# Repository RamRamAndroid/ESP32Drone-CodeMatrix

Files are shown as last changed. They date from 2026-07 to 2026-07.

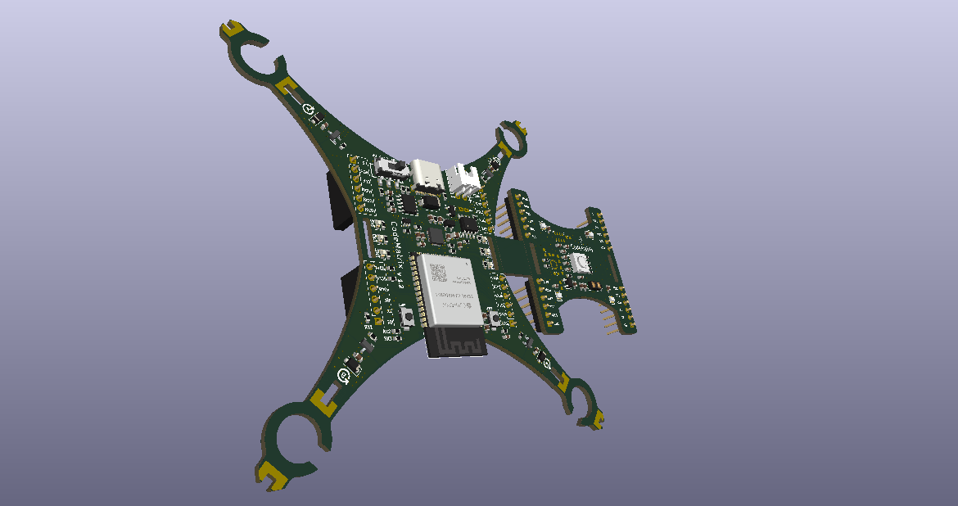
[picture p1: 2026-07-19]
Drone + Module/KiCad Files/panel.png

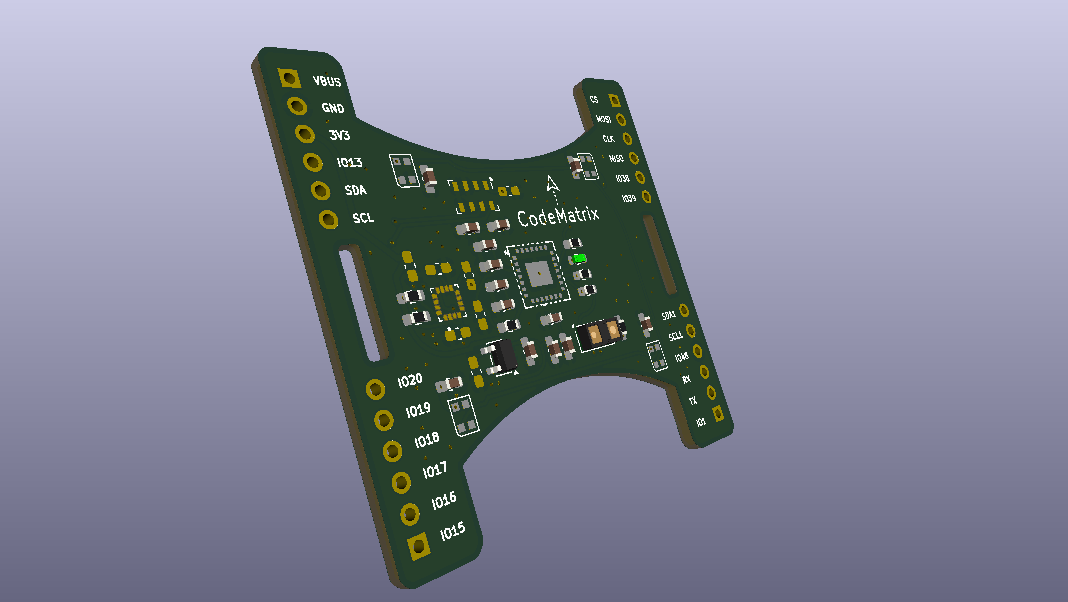
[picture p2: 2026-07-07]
Module/KiCAD Files/B1.png

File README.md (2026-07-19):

## Introduction Of CodeMatrix ESP32 Drone
drone
drone

CodeMatrix ESP32 Drone is a compact, WiFi-controlled drone based on the ESP32-S3 microcontroller. Designed for hobbyists, makers, and engineers, CodeMatrix ESP32 Drone offers a simple yet powerful platform for drone experimentation and development. It is an open-hardware project, making it easy to modify and expand.

Whether you’re new to drones or an experienced developer looking to create custom flight applications, LiteWing provides an accessible and affordable way to explore drone technology. Unlike traditional drones that require proprietary controllers, CodeMatrix ESP32 Drone connects to your smartphone, allowing for an intuitive flying experience without additional hardware.

The firmware on CodeMatrix ESP32 Drone supports Crazyflie cfclient and cflib, meaning you can program and control your drone using Python and add more features like height hold, position hold, gesture control, and more.

The latest version includes more GPIO pins, sensor mounts, LED indicators to make it easier to tinker with and program. The PCB frame design keeps it lightweight while reducing costs, making it one of the most affordable DIY drones available.

### Note:- The Files Related To The Drone Are In The Folder Named "Drone"

## Introduction Of CodeMatrix ESP32 Drone Positioning Module
WhatsApp Image 2026-07-04 at 12 35 27 AM
B-ezgif com-optimize (1)

The ESP32 Drone Positioning Module is a plug-and-play optical flow and ToF-based stabilization add-on designed for indoor and GPS-denied flight. Featuring the PMW3901 optical flow sensor for precise X/Y position tracking and the VL53L1X Time-of-Flight sensor for accurate height measurement, this module enables stable height hold and position hold performance. Ideal for DIY drones, autonomous flight experiments, and educational robotics projects.

This module transforms your CodeMatrix ESP32 Drone and Litewing Drone into a fully-equipped autonomous flight platform by adding critical sensor capabilities: precision ToF height measurement, optical motion tracking, and visual status feedback. All connected through a 24-pin connector, eliminating complex wiring while maintaining robust electrical connections suitable for flight operations.

This add-on module is completely compatible with the CodeMatrix ESP32 Drone and LiteWing Drones and consists of the VL53L1x ToF sensor and PMW3901MB optical flow sensor for height hold and position hold, respectively. Apart from this, the module also has 4 Neopixel LEDs that can be programmed to indicate flight status or for visual appeal.

Important: By default, only the ToF sensor, Optical Flow sensor, and Neopixel LEDs will be soldered on the module. The brometric sensor and magnetometer footprint is added only for users who wish to build more using the same board. By default these two sensors will not be populated. The colour of the PCB might also be in black or green color depending on the time of purchase, but features and working will reamin the same.

### Note:- Files Related To The Positioning Module Are In The Folder Named "Module"

## Introduction Of ESP32 Drone Bluetooth Speaker Module (Coming Soon)

untitled-ezgif com-optimize

The ESP32 Drone Bluetooth Speaker Module is a plug-and-play lightweight Bluetooth speaker system to extend the drone's capabilities beyond flight. By adding a simple Bluetooth audio setup, the drone can now deliver real-time announcements, voice messages, or music directly from the air without requiring any additional coding. The entire system works through a standard Bluetooth connection, making it easy to set up, practical for demonstrations, events, and experimental applications while also being fun.

### Note:- Files Related To The Positioning Module Are In The Folder Named "BluetoothModule"

## Introduction Of ESP32 Drone + Positioning Module PCB
panel
panel

This PCB Has Both The Drone And Module Combined Into One PCB For Easier Manufacturing And Assembly And This Method Is Faster Than Getting The Both Seperatly

### Note:- The Files Related To The Drone + Module PCB Are In The Folder Named "drone+module"

## Add-On Module Template



I Have Made A Template Of The Positioning Module For You To Customize, It Is In The Module Folder

-------------------------------------------------------------------------------------------------------------------------------------------------

### As This Project Is Based On LiteWing, The Instructions Are The Same As Litewing Drone Instructions (https://circuitdigest.com/wiki/litewing/)

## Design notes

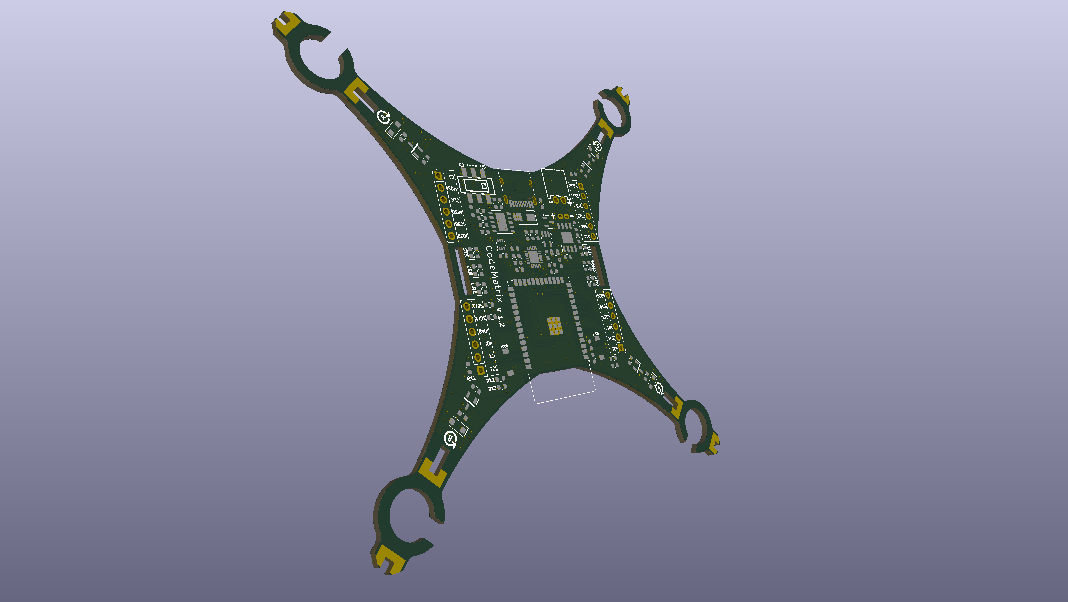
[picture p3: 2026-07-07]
Drone/KiCAD Files/drone.png

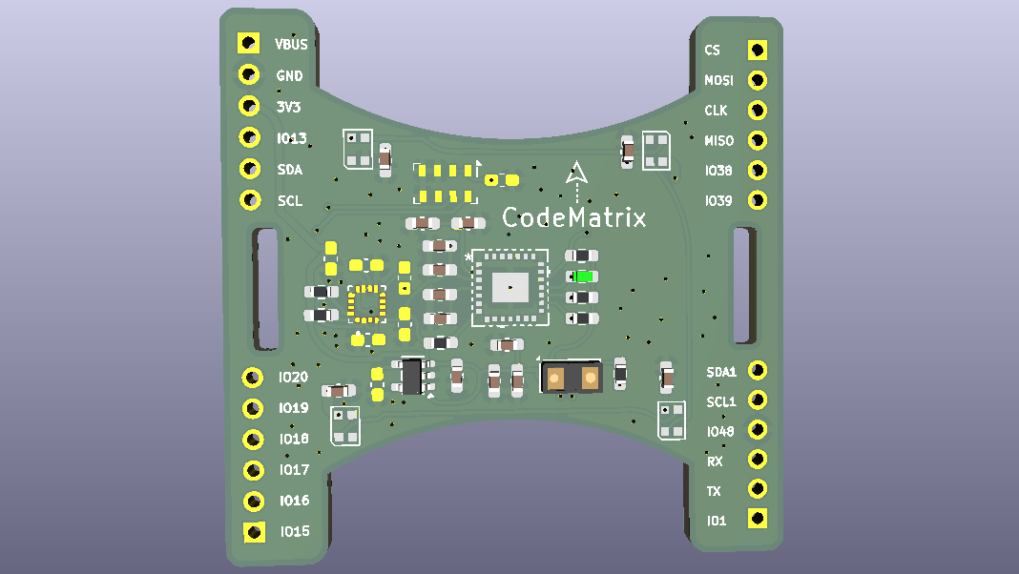
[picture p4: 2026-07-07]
Module/KiCAD Files/B.png

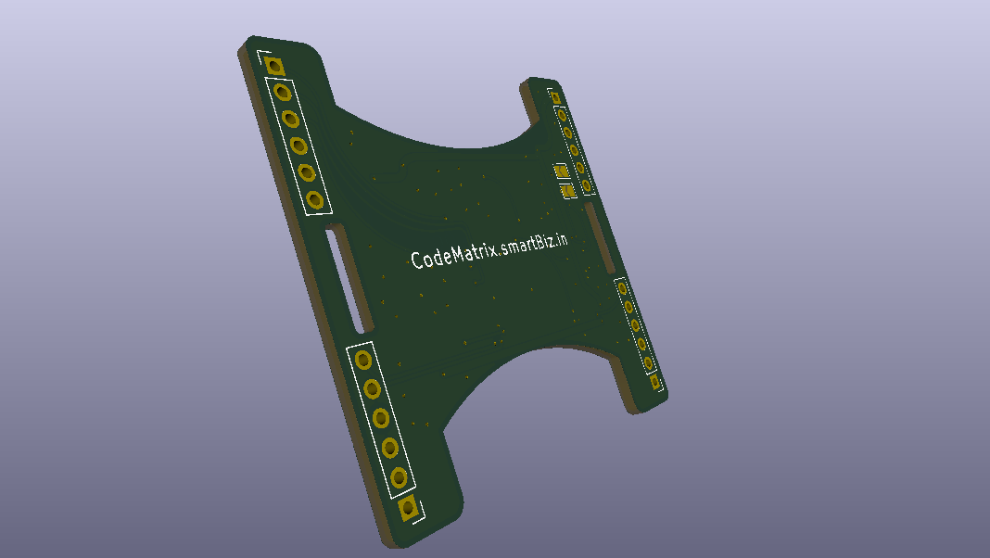
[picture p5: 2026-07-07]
Module/KiCAD Files/B3.png

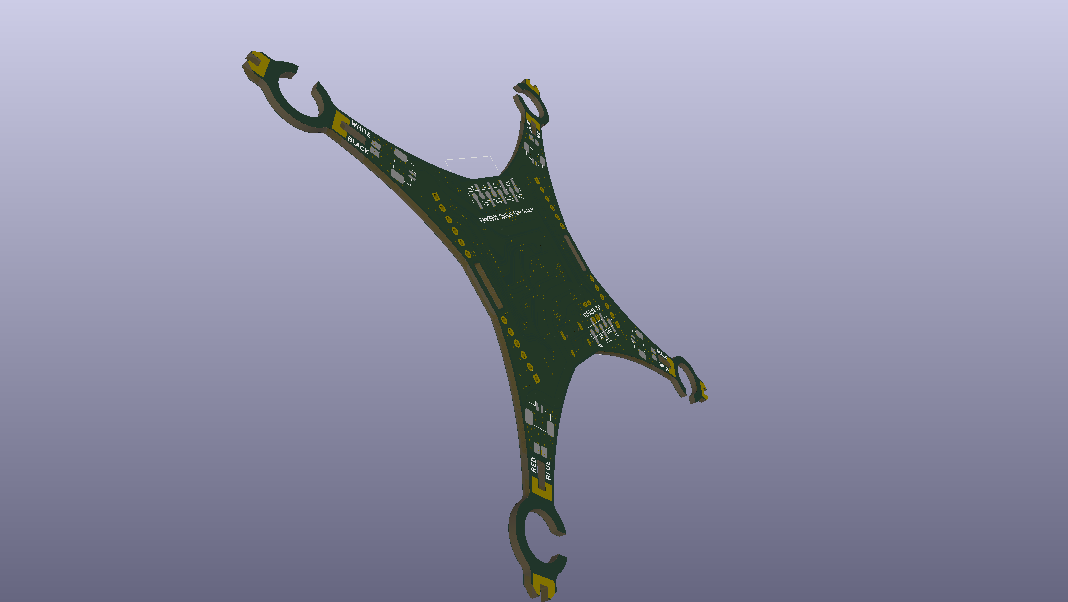
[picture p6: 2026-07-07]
Drone/KiCAD Files/drone1.png

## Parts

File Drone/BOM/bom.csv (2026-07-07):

Designator | Footprint | Quantity | Value | LCSC Part #
C1, C12, C4, C5 | 0603 | 4 | 10uF | C19702
C10, C13, C14, C6, C7, C8 | 0603 | 6 | 100nF | C14663
C11 | 0603 | 1 | 10nf | C57112
C15, C16, C17, C18 | 0603 | 4 | 1uF | C15849
C2 | 0603 | 1 | 470pF | C1620
C3 | 0805 | 1 | 2.2uF | C5448893
C9 | 0603 | 1 | 2.2nf | C1604
D1 | D_SMA | 1 | SS34 | C8678
D2, D3, D4, D5 | D_SOD-123F | 4 | 1N4148W | C81598
IC1 | SOIC127P600X175-9N | 1 | TP4056 | C20199357
J1 | USB_C_Receptacle_HRO_TYPE-C-31-M-12 | 1 | USB_C_Receptacle_USB2.0 | C2927038
J2 | CONN-TH_2P-P2.50_XH-2AW | 1 | JST XH 2P 2.50mm SMD Hoz | C33132
LED1, LED2, LED5 | 0603 | 3 | LED_Red | C2286
LED3, LED6 | 0603 | 2 | LED_Blue | C2288
LED4 | 0603 | 1 | LED_Green | C12065
R1, R2 | 0603 | 2 | 5.1K | C23186
R10, R11, R12, R13, R6, R7, R9 | 0603 | 7 | 1K | C21190
R14, R16, R17, R18, R19, R20, R21, R22, R23, R24, R25 | 0603 | 11 | 10k | C25804
R15 | 0603 | 1 | 4.7k | C23162
R26, R27, R3, R8 | 0603 | 4 | 100K | C25803
R28, R29, R30 | 0603 | 3 | 0R | C21189
R4 | 0603 | 1 | 470R | C23179
R5 | 0603 | 1 | 1.2K | C22765
SW1 | SW-SMD_MST22D18G2 | 1 | MST22D18G2_125 | C2906280
SW2, SW3 | Tactile 3x4x2mm TS-A010 | 2 | Tactile Switch 3x4x2 | C2874433
T1, T2, T3, T4 | SOT95P237X112-3N | 4 | IRLML6344TRPBF | C6285738
U1 | SOT-23 | 1 | AO3401A | C15127
U2 | SOT-23-5 | 1 | SPX3819M5-L-3-3/TR | C9055
U5 | ESSOP-10_3.9x4.9mm_P1.00mm | 1 | CH340K | C18208922
U6 | SOT-363_SC-70-6 | 1 | 2N27002DW | C5190214
U7 | MPU6050 | 1 | MPU-6050 | C24112
U8 | ESP32-S3-WROOM-1 | 1 | ESP32-S3-WROOM-1 | C2913198

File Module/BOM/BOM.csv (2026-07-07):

Id | Designator | Footprint | Quantity | Designation | Supplier and ref
1 | C1, C3, C5 | C_0603_1608Metric_Pad1.08x0.95mm_HandSolder | 3 | 10uF
2 | C4, C6, C8, C10, C11 | C_0603_1608Metric_Pad1.08x0.95mm_HandSolder | 5 | 0.1uF
3 | C7, C9 | C_0603_1608Metric_Pad1.08x0.95mm_HandSolder | 2 | 4.7uF
4 | C18, C19, C20, C21 | C_0603_1608Metric_Pad1.08x0.95mm_HandSolder | 4 | 1uF
5 | D1, D2, D3, D4 | LED_WS2812B-2020_PLCC4_2.0x2.0mm | 4 | WS2812B-2020
6 | R1, R8 | R_0603_1608Metric_Pad0.98x0.95mm_HandSolder | 2 | 4.7K
7 | R2, R3, R4, R5, R6, R7 | R_0603_1608Metric_Pad0.98x0.95mm_HandSolder | 6 | 10K
8 | U1 | SOT-23-5 | 1 | SPX3819M5-L-1-8
9 | U2 | QFN_01MB-TXQT_PIX | 1 | PMW3901MB-TXQT
10 | U3 | ST_VL53L1x | 1 | VL53L1CXV0FY1

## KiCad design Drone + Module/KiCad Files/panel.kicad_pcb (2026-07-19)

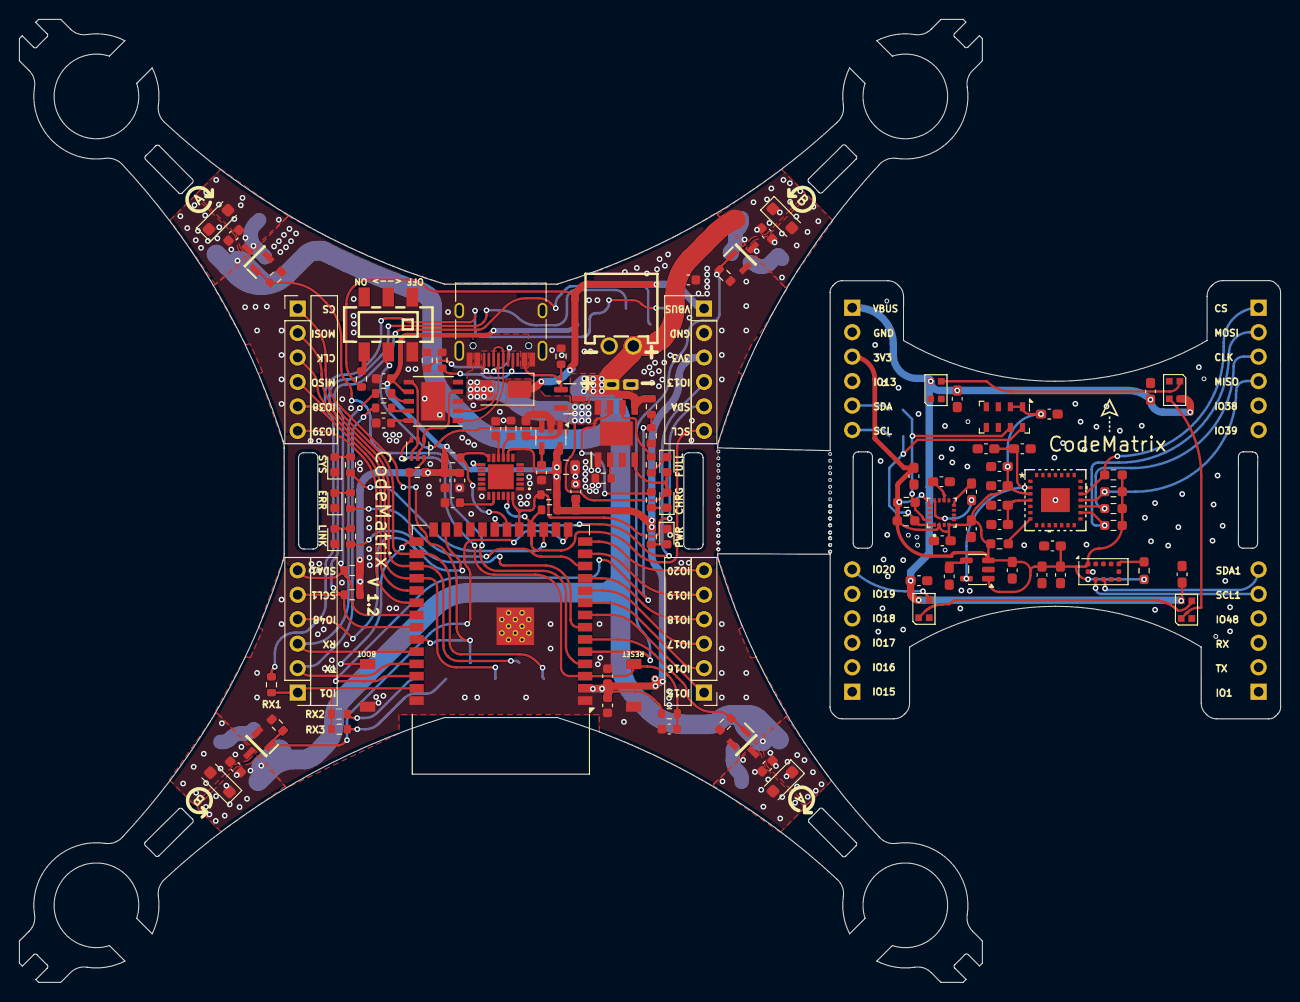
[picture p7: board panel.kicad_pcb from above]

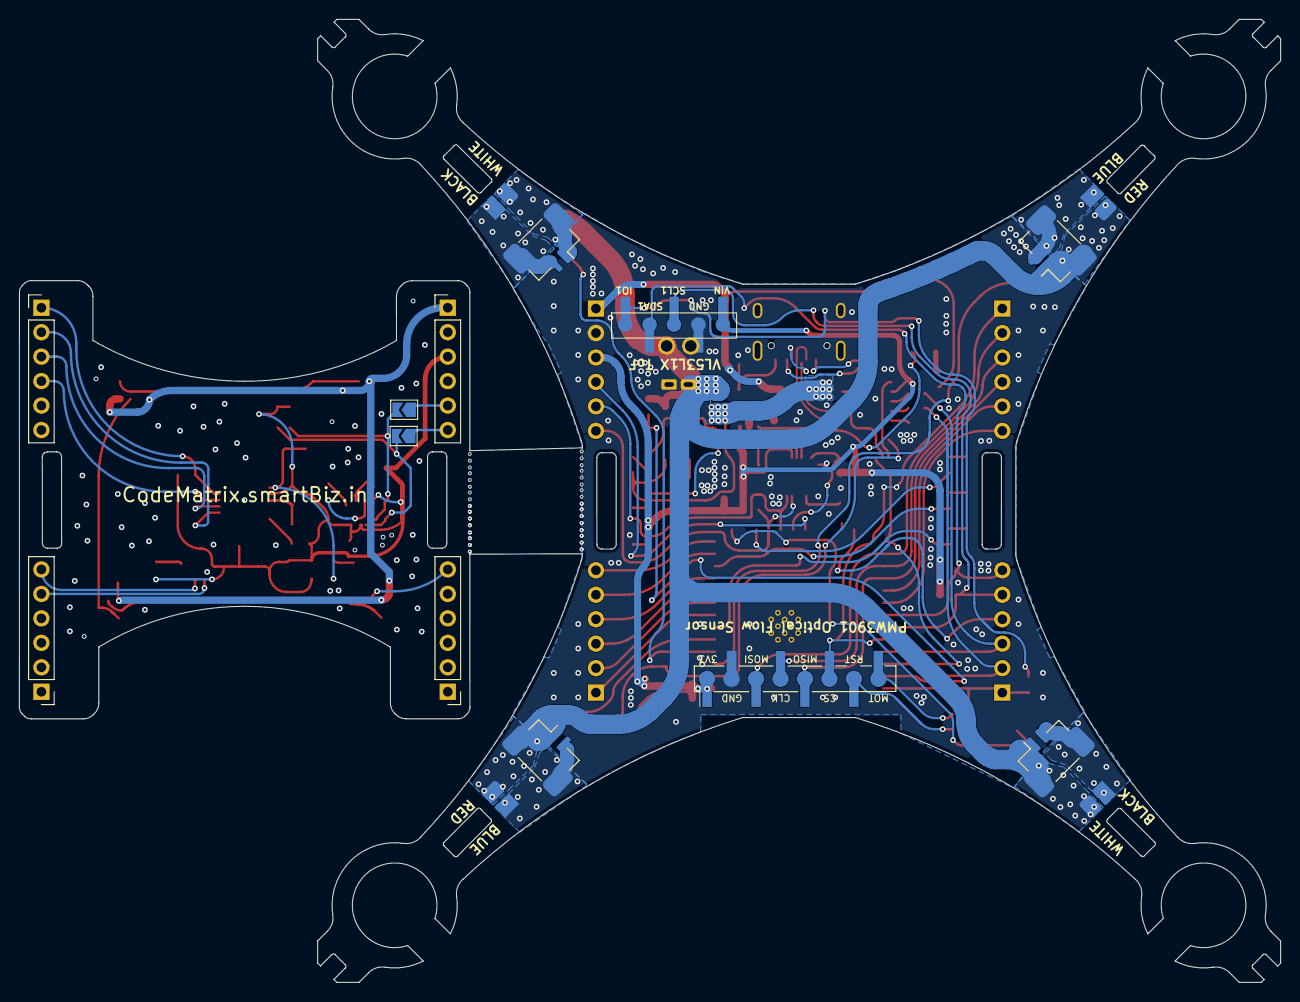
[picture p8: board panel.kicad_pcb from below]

Board: 2 copper layers, 131.0 x 100.0 mm, 129 parts (8 on the bottom side), 82 nets.

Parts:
C1, C4, C5#2, C12: 10uF; C_0603_1608Metric
C1#2, C2#2, C3#2, C5: 10uF; C_0603_1608Metric_Pad1.08x0.95mm_HandSolder
C2: 470pF; C_0603_1608Metric
C3: 2.2uF; C_0805_2012Metric
C4#2, C6, C8#2, C10#2, C11, C12#2, C13, C14#2, C15#2: 0.1uF; C_0603_1608Metric_Pad1.08x0.95mm_HandSolder
C6#2, C7#2, C8, C10, C13#2, C14: 100nF; C_0603_1608Metric
C7, C9#2, C16: 4.7uF; C_0603_1608Metric_Pad1.08x0.95mm_HandSolder
C9: 2.2nf; C_0603_1608Metric
C11#2: 10nf; C_0603_1608Metric
C15, C16#2, C17#2, C18#2: 1uF; C_0603_1608Metric
C17: 0.22uF; C_0603_1608Metric_Pad1.08x0.95mm_HandSolder
C18, C19, C20, C21: 1uF; C_0603_1608Metric_Pad1.08x0.95mm_HandSolder
D1, D2#2, D3, D4#2: WS2812B-2020; LED_WS2812B-2020_PLCC4_2.0x2.0mm
D1#2: SS34; D_SMA
D2, D3#2, D4, D5: 1N4148W; D_SOD-123F
IC1: TP4056; SOIC127P600X175-9N
J1: USB_C_Receptacle_USB2.0; USB_C_Receptacle_HRO_TYPE-C-31-M-12
J2: JST XH 2P 2.50mm SMD Hoz; CONN-TH_2P-P2.50_XH-2AW
J3, J3#2, J4, J4#2, J5, J5#2, J6, J6#2: Conn_01x06; PinHeader_1x06_P2.54mm_Vertical
J7, J8, J9, J10: Conn_01x02_Female; LiteWingMotor2
J11: Conn_01x09; PMW3901
J12: Conn_01x06; VL53L1X_BREAKOUT
JP1, JP2: SolderJumper_2_Open; SolderJumper-2_P1.3mm_Open_TrianglePad1.0x1.5mm
LED1, LED2, LED5: LED_Red; LED_0603_1608Metric
LED3, LED6: LED_Blue; LED_0603_1608Metric
LED4: LED_Green; LED_0603_1608Metric
R1, R2: 5.1K; R_0603_1608Metric
R1#2, R8: 4.7K; R_0603_1608Metric_Pad0.98x0.95mm_HandSolder
R2#2, R3, R4, R5#2, R6, R7: 10K; R_0603_1608Metric_Pad0.98x0.95mm_HandSolder
R3#2, R8#2, R26, R27: 100K; R_0603_1608Metric
R4#2: 470R; R_0603_1608Metric
R5: 1.2K; R_0603_1608Metric
R6#2, R7#2, R9, R10, R11, R12, R13: 1K; R_0603_1608Metric
R14, R16, R17, R18, R19, R20, R21, R22, R23, R24, R25: 10k; R_0603_1608Metric
R15: 4.7k; R_0603_1608Metric
R28, R29, R30: 0R; R_0603_1608Metric
SW1: MST22D18G2_125; SW-SMD_MST22D18G2
SW2, SW3: Tactile Switch 3x4x2; Tactile 3x4x2mm TS-A010
T1, T2, T3, T4: IRLML6344TRPBF; SOT95P237X112-3N
U1: AO3401A; SOT-23
U1#2: SPX3819M5-L-1-8; SOT-23-5
U2: PMW3901MB-TXQT; QFN_01MB-TXQT_PIX
U2#2: SPX3819M5-L-3-3/TR; SOT-23-5
U3: VL53L1CXV0FY1; ST_VL53L1x
U4: MS5611-01BA; LGA-8_3x5mm_P1.25mm
U5: HMC5883L-TR; XDCR_HMC5883L-TR
U5#2: CH340K; ESSOP-10_3.9x4.9mm_P1.00mm
U6: 2N27002DW; SOT-363_SC-70-6
U7: MPU-6050; MPU6050
U8: ESP32-S3-WROOM-1

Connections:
+2V0: C3#2.1, C4#2.1, U1#2.5 (OUT), U2.2 (VDD)
+3V3: C3.1, C4.1, C7#2.1, C10.1, C11#2.1, C12.1, C13#2.1, J4.3, J11.1, J12.1, R4#2.2, R14.2, R16.2, R17.2, R18.2, R19.2, R20.2, R21.2, U2#2.5 (OUT), U5#2.7 (VCC), U7.8 (VLOGIC), U7.13 (VDD), U8.2 (3V3)
+5V: D1#2.2 (A), IC1.4 (VCC), IC1.8 (CE), J1.A4 (VBUS), J1.A9 (VBUS), J1.B4 (VBUS), J1.B9 (VBUS), LED2.2 (A), LED3.2 (A), R3#2.1, U1.1 (G)
+BATT: C5#2.1, C15.1, C16#2.1, C17#2.1, C18#2.1, D2.1 (K), D3#2.1 (K), D4.1 (K), D5.1 (K), IC1.5 (BAT), J2.1, J7.1, J8.1, J9.1, J10.1, R26.1, U1.3 (D)
/ADC_BAT: R26.2, R27.1, U8.38 (IO2)
/BUZ1: J6.5, J6#2.5, U8.31 (IO38)
/BUZ2: J6.6, J6#2.6, U8.32 (IO39)
/CLK: J6.3, J6#2.3, J11.4, R5#2.1, U2.17 (SCLK), U8.29 (IO36)
/CS: J6.1, J6#2.1, J11.6, R3.1, U2.19 (NCS), U8.35 (IO42)
/D+: J1.A6 (D+), J1.B6 (D+), U5#2.1 (D+)
/D-: J1.A7 (D-), J1.B7 (D-), U5#2.2 (D-)
/DTR: U5#2.4 (DTR), U6.2, U6.4
/EN: C14.1, R18.1, SW3.2, U6.6, U8.3 (EN)
/IO0: R19.1, SW2.2, U6.3, U8.27 (IO0)
/IO1: J5.1, J5#2.1, R28.1, R29.1, R30.1, U8.39 (IO1)
/IO13: J4.4, J4#2.4, U8.21 (IO13)
/IO15: J3.1, J3#2.1, U8.8 (IO15)
/IO16: J3.2, J3#2.2, U8.9 (IO16)
/IO17: J3.3, J3#2.3, U8.10 (IO17)
/IO18: J3.4, J3#2.4, U8.11 (IO18)
/IO19: J3.5, J3#2.5, U8.13 (IO19)
/IO20: D1.3 (DIN), J3.6, J3#2.6, U8.14 (IO20)
/IO48: J5.4, U8.25 (IO48)
/LDO_H: R8#2.2, SW1.3
/LED_BLUE: R13.2, U8.7 (IO7)
/LED_GREEN: R11.2, U8.17 (IO9)
/LED_RED: R12.2, U8.12 (IO8)
/MISO: J6.4, J6#2.4, J11.5, R4.1, U2.18 (MISO), U8.30 (IO37)
/MOSI: J6.2, J6#2.2, J11.3, R6.1, U2.16 (MOSI), U8.28 (IO35)
/MOT_1: R22.2, T1.1 (G), U8.5 (IO5)
/MOT_2: R23.2, T2.1 (G), U8.6 (IO6)
/MOT_3: R24.2, T3.1 (G), U8.15 (IO3)
/MOT_4: R25.2, T4.1 (G), U8.4 (IO4)
/MPU_INT: R17.1, U7.12 (INT), U8.20 (IO12)
/RTS: U5#2.6 (RTS), U6.1, U6.5
/RX: J5.3, J5#2.3, R10.1, U8.36 (RXD0)
/SCL: J4.6, JP2.2 (B), R8.1, R16.1, U4.8 (SCLK), U5.1 (SCL), U7.23 (SCL), U8.18 (IO10)
/SCL1: J5.5, J5#2.5, J12.3, R21.1, U3.10 (SCL), U8.34 (IO41)
/SDA: J4.5, JP1.2 (B), R1#2.1, R14.1, U4.7 (SDI/SDA), U5.16 (SDA), U7.24 (SDA), U8.19 (IO11)
/SDA1: J5.6, J5#2.6, J12.4, R20.1, U3.9 (SDA), U8.33 (IO40)
/TX: J5.2, J5#2.2, R9.1, U8.37 (TXD0)
GND: C1.2, C1#2.2, C2.2, C2#2.2, C3.2, C3#2.2, C4.2, C4#2.2, C5.2, C5#2.2, C6.2, C6#2.1, C7.2, C7#2.2, C8.2, C8#2.2, C9.2, C9#2.2, C10.2, C10#2.2, C11.2, C11#2.2, C12.2, C12#2.1, C13.1, C13#2.2, C14.2, C14#2.1, C15#2.1, C16.1, C18.2, C19.2, C20.2, C21.2, D1.2 (VSS), D2#2.2 (VSS), D3.2 (VSS), D4#2.2 (VSS), IC1.1 (TEMP), IC1.3 (GND), IC1.9 (EP), J1.A1 (GND), J1.A12 (GND), J1.B1 (GND), J1.B12 (GND), J1.S1 (SHIELD), J2.2, J4.2, J4#2.2, J5#2.4, J11.2, J12.2, LED1.1 (K), LED4.1 (K), LED5.1 (K), LED6.1 (K), R1.2, R2.2, R3#2.2, R5.2, R15.1, R22.1, R23.1, R24.1, R25.1, R27.2, SW1.1, SW1.4, SW2.1, SW3.1, T1.2 (S), T2.2 (S), T3.2 (S), T4.2 (S), U1#2.2 (GND), U2.1 (GND), U2.21 (GND), U2.29 (GND), U2#2.2 (GND), U3.2 (AVSSVCSEL), U3.3 (GND), U3.4 (GND), U3.6 (GND), U3.12 (GND), U4.3 (GND), U4.4 (CSB), U4.5 (CSB), U5.9 (GND), U5.11 (GND), U5#2.3 (GND), U5#2.11 (EP), U7.1 (CLKIN), U7.11 (FSYNC), U7.18 (GND), U8.1 (GND), U8.40 (GND), U8.41 (GND)
LDO_EN: SW1.2, U2#2.3 (EN)
unnamed: D1.1 (DOUT), D2#2.3 (DIN)
unnamed: C15.2, D2.2 (A), J7.2, T1.3 (D)
unnamed: D2#2.1 (DOUT), D3.3 (DIN)
unnamed: C16#2.2, D3#2.2 (A), J8.2, T2.3 (D)
unnamed: D3.1 (DOUT), D4#2.3 (DIN)
unnamed: C17#2.2, D4.2 (A), J9.2, T3.3 (D)
unnamed: C18#2.2, D5.2 (A), J10.2, T4.3 (D)
unnamed: IC1.2 (PROG), R5.1
unnamed: IC1.7 (~CHRG), R6#2.2
unnamed: IC1.6 (~STDBY), R7#2.2
unnamed: J1.A5 (CC1), R2.1
unnamed: J1.B5 (CC2), R1.1
unnamed: J4#2.5, JP1.1 (A)
unnamed: J4#2.6, JP2.1 (A)
unnamed: J11.7, R29.2
unnamed: J11.8, R30.2
unnamed: J12.5, R28.2
unnamed: LED1.2 (A), R4#2.1
unnamed: LED2.1 (K), R6#2.1
unnamed: LED3.1 (K), R7#2.1
unnamed: LED4.2 (A), R11.1
unnamed: LED5.2 (A), R12.1
unnamed: LED6.2 (A), R13.1
unnamed: C2#2.1, U1#2.4 (BP)
unnamed: C2.1, U2#2.4 (BP)
unnamed: R2#2.2, U2.7 (NRESET)
unnamed: C7.1, C8#2.1, U2.4 (VREG)
unnamed: R7.2, U3.5 (XSHUT)
unnamed: C16.2, U5.10 (C1)
unnamed: R9.2, U5#2.9 (RXD)
unnamed: C17.2, U5.12 (SETC)
unnamed: C17.1, U5.8 (SETP)
unnamed: R10.2, U5#2.8 (TXD)
unnamed: C6#2.2, U5#2.10 (V3)
unnamed: R15.2, U7.9 (AD0)
unnamed: C9.1, U7.20 (CPOUT)
unnamed: C8.1, U7.10 (REGOUT)
VBUS: C1.1, C18.1, C19.1, C20.1, C21.1, D1.4 (VDD), D1#2.1 (K), D2#2.4 (VDD), D3.4 (VDD), D4#2.4 (VDD), J4.1, J4#2.1, R8#2.1, U1.2 (S), U2#2.1 (IN)
VDD: C1#2.1, C5.1, C6.1, C9#2.1, C10#2.1, C11.1, C12#2.2, C13.2, C14#2.2, C15#2.2, J4#2.3, R1#2.2, R2#2.1, R3.2, R4.2, R5#2.2, R6.2, R7.1, R8.2, U1#2.1 (IN), U1#2.3 (EN), U2.3 (VDDIO), U3.1 (AVDDVCSEL), U3.11 (AVDD), U4.1 (VDD), U4.2 (PS), U5.2 (VDD), U5.4 (S1), U5.13 (VDDIO)

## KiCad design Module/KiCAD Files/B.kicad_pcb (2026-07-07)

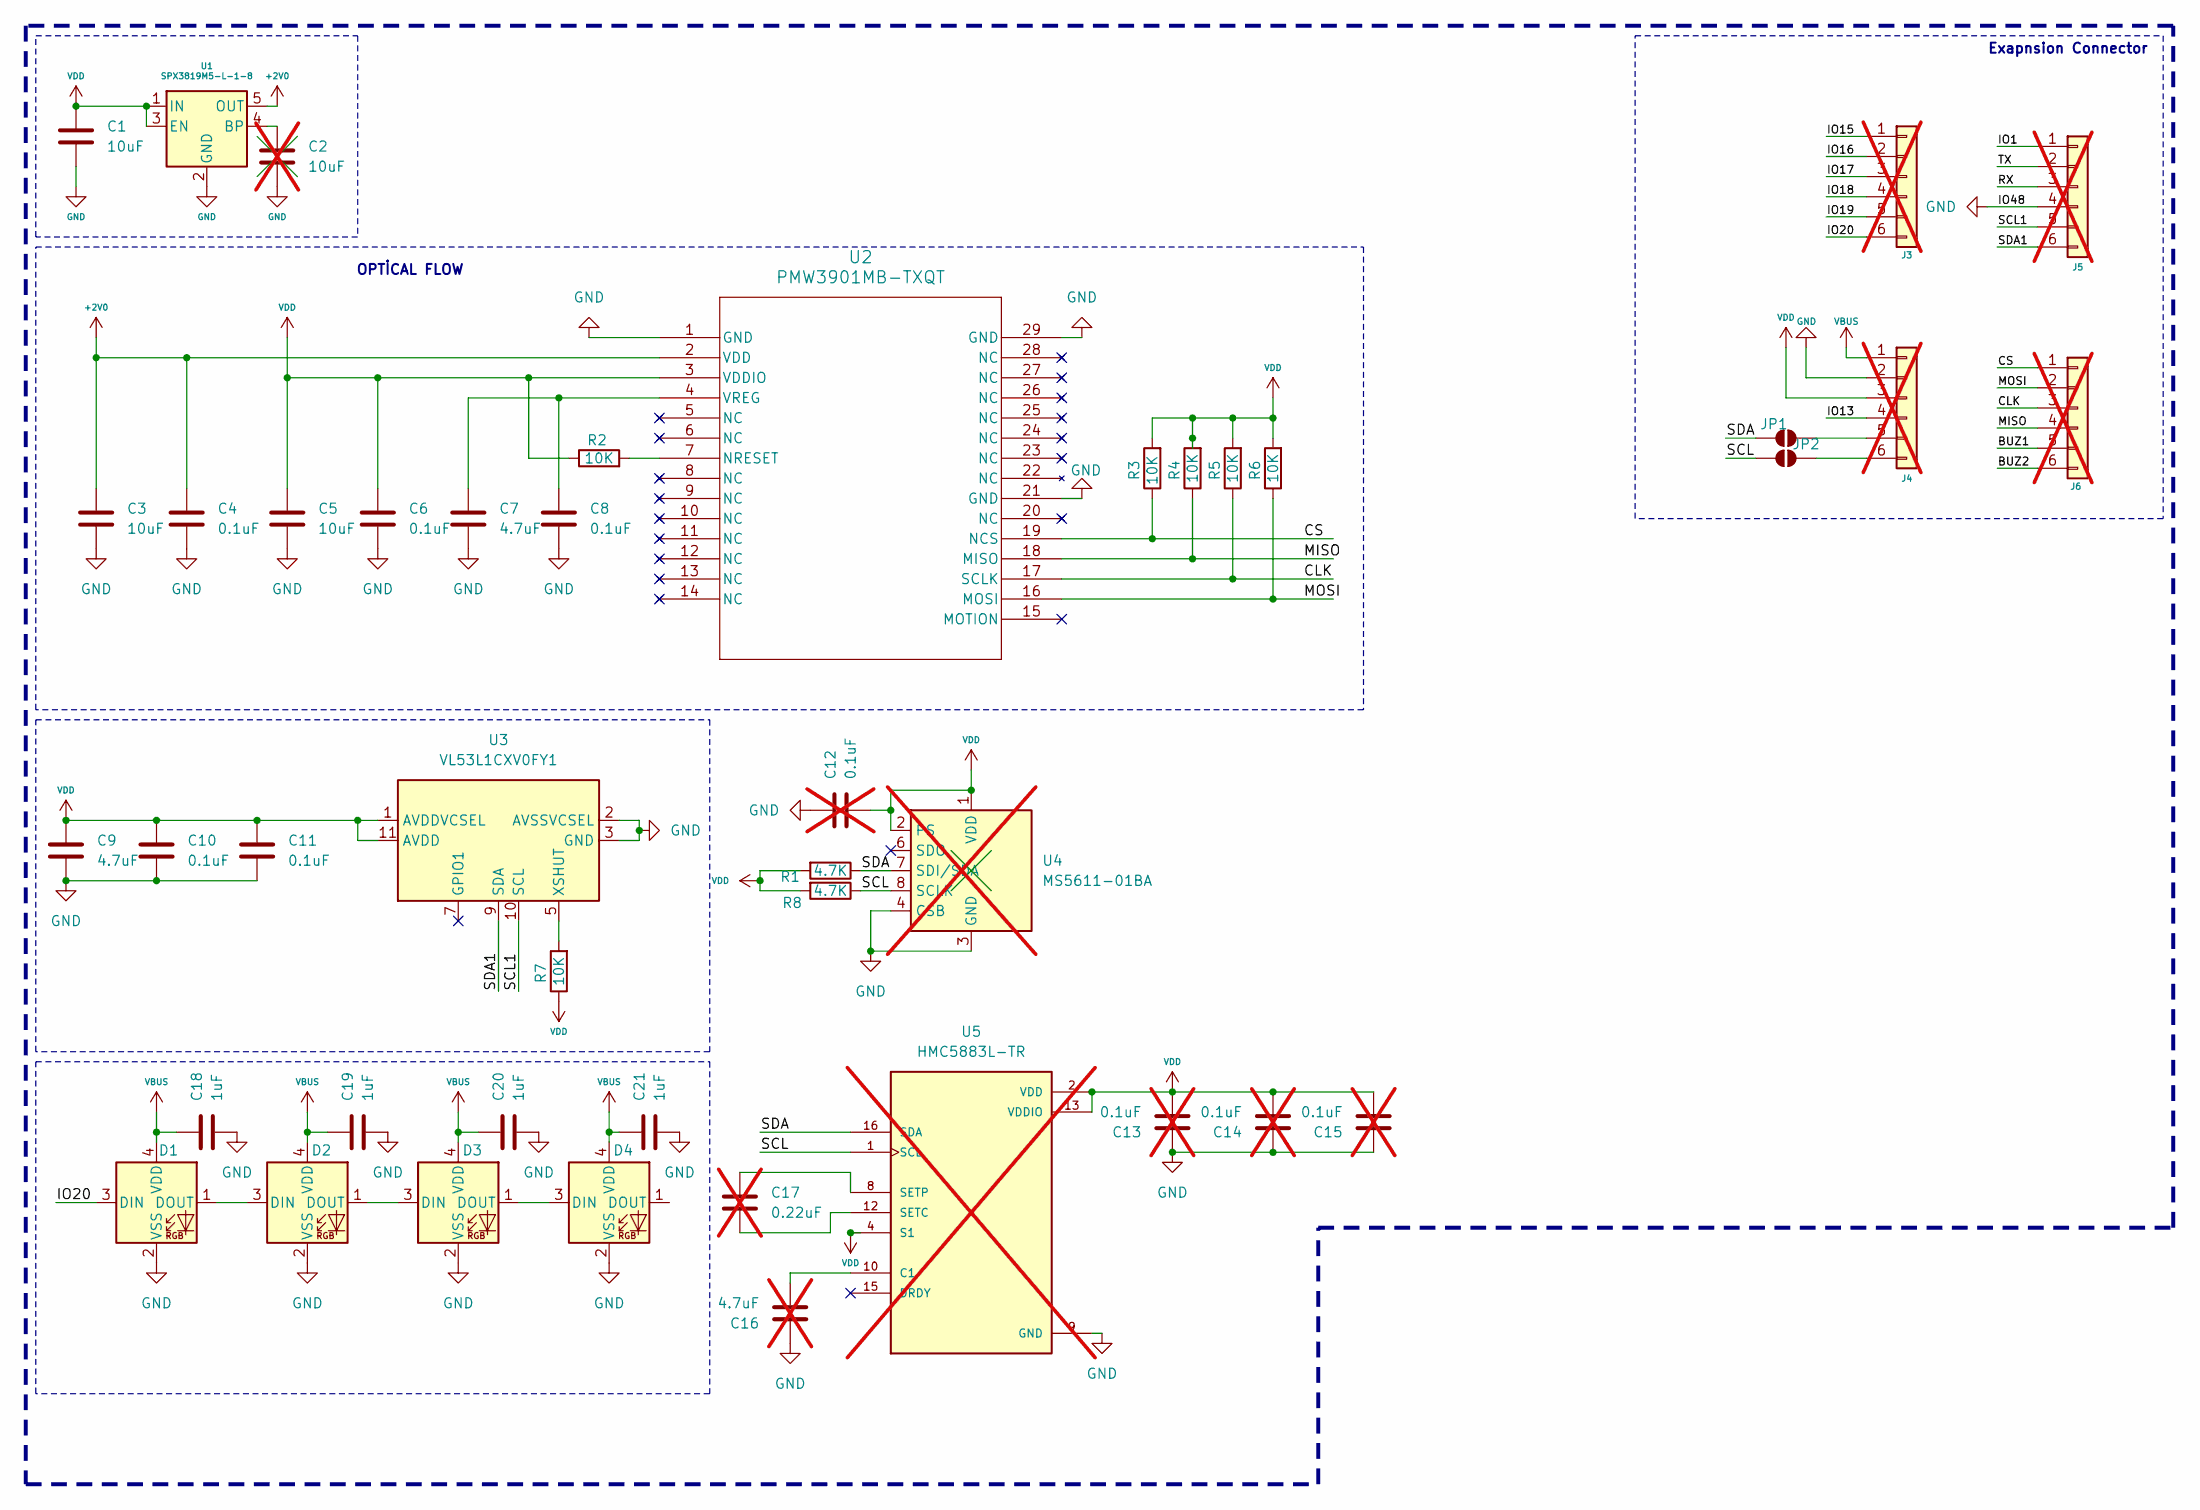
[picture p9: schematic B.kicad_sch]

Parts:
C1, C3, C5: 10uF; C_0603_1608Metric_Pad1.08x0.95mm_HandSolder
C2: 10uF; C_0603_1608Metric_Pad1.08x0.95mm_HandSolder; not fitted
C4, C6, C8, C10, C11: 0.1uF; C_0603_1608Metric_Pad1.08x0.95mm_HandSolder
C7, C9: 4.7uF; C_0603_1608Metric_Pad1.08x0.95mm_HandSolder
C12, C13, C14, C15: 0.1uF; C_0603_1608Metric_Pad1.08x0.95mm_HandSolder; not fitted
C16: 4.7uF; C_0603_1608Metric_Pad1.08x0.95mm_HandSolder; not fitted
C17: 0.22uF; C_0603_1608Metric_Pad1.08x0.95mm_HandSolder; not fitted
C18, C19, C20, C21: 1uF; C_0603_1608Metric_Pad1.08x0.95mm_HandSolder
D1, D2, D3, D4: WS2812B-2020; LED_WS2812B-2020_PLCC4_2.0x2.0mm
J3, J4, J5, J6: Conn_01x06; PinHeader_1x06_P2.54mm_Vertical; not fitted
JP1, JP2: SolderJumper_2_Open; SolderJumper-2_P1.3mm_Open_TrianglePad1.0x1.5mm
R1, R8: 4.7K; R_0603_1608Metric_Pad0.98x0.95mm_HandSolder
R2, R3, R4, R5, R6, R7: 10K; R_0603_1608Metric_Pad0.98x0.95mm_HandSolder
U1: SPX3819M5-L-1-8; SOT-23-5
U2: PMW3901MB-TXQT; QFN_01MB-TXQT_PIX
U3: VL53L1CXV0FY1; ST_VL53L1x
U4: MS5611-01BA; LGA-8_3x5mm_P1.25mm; not fitted
U5: HMC5883L-TR; XDCR_HMC5883L-TR; PARTREV E; not fitted

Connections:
+2V0: C3.1, C4.1, U1.5 (OUT), U2.2 (VDD)
/BUZ1: J6.5
/BUZ2: J6.6
/CLK: J6.3, R5.1, U2.17 (SCLK)
/CS: J6.1, R3.1, U2.19 (NCS)
/IO1: J5.1
/IO13: J4.4
/IO15: J3.1
/IO16: J3.2
/IO17: J3.3
/IO18: J3.4
/IO19: J3.5
/IO20: D1.3 (DIN), J3.6
/MISO: J6.4, R4.1, U2.18 (MISO)
/MOSI: J6.2, R6.1, U2.16 (MOSI)
/RX: J5.3
/SCL: JP2.2 (B), R8.1, U4.8 (SCLK), U5.1 (SCL)
/SCL1: J5.5, U3.10 (SCL)
/SDA: JP1.2 (B), R1.1, U4.7 (SDI/SDA), U5.16 (SDA)
/SDA1: J5.6, U3.9 (SDA)
/TX: J5.2
GND: C1.2, C2.2, C3.2, C4.2, C5.2, C6.2, C7.2, C8.2, C9.2, C10.2, C11.2, C12.1, C13.1, C14.1, C15.1, C16.1, C18.2, C19.2, C20.2, C21.2, D1.2 (VSS), D2.2 (VSS), D3.2 (VSS), D4.2 (VSS), J4.2, J5.4, U1.2 (GND), U2.1 (GND), U2.21 (GND), U2.29 (GND), U3.2 (AVSSVCSEL), U3.3 (GND), U3.4 (GND), U3.6 (GND), U3.12 (GND), U4.3 (GND), U4.4 (CSB), U4.5 (CSB), U5.9 (GND), U5.11 (GND)
unnamed: D1.1 (DOUT), D2.3 (DIN)
unnamed: D2.1 (DOUT), D3.3 (DIN)
unnamed: D3.1 (DOUT), D4.3 (DIN)
unnamed: J4.5, JP1.1 (A)
unnamed: J4.6, JP2.1 (A)
unnamed: C2.1, U1.4 (BP)
unnamed: R2.2, U2.7 (NRESET)
unnamed: C7.1, C8.1, U2.4 (VREG)
unnamed: R7.2, U3.5 (XSHUT)
unnamed: C16.2, U5.10 (C1)
unnamed: C17.2, U5.12 (SETC)
unnamed: C17.1, U5.8 (SETP)
VBUS: C18.1, C19.1, C20.1, C21.1, D1.4 (VDD), D2.4 (VDD), D3.4 (VDD), D4.4 (VDD), J4.1
VDD: C1.1, C5.1, C6.1, C9.1, C10.1, C11.1, C12.2, C13.2, C14.2, C15.2, J4.3, R1.2, R2.1, R3.2, R4.2, R5.2, R6.2, R7.1, R8.2, U1.1 (IN), U1.3 (EN), U2.3 (VDDIO), U3.1 (AVDDVCSEL), U3.11 (AVDD), U4.1 (VDD), U4.2 (PS), U5.2 (VDD), U5.4 (S1), U5.13 (VDDIO)

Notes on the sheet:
OPTİCAL FLOW
Exapnsion Connector

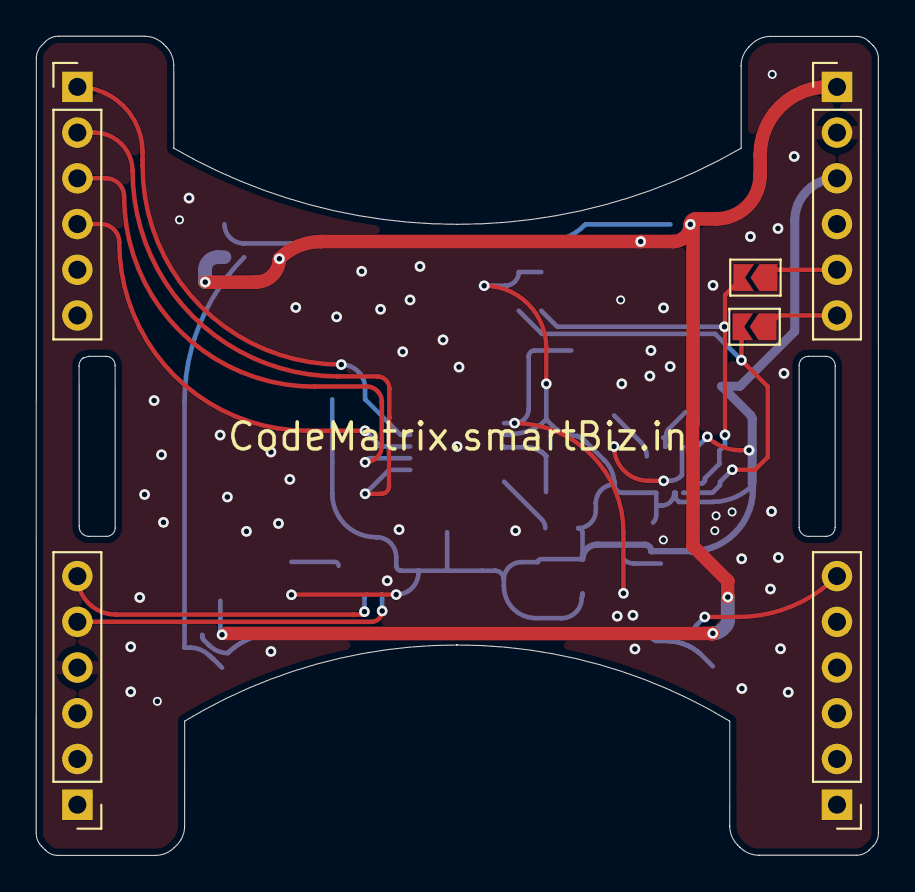
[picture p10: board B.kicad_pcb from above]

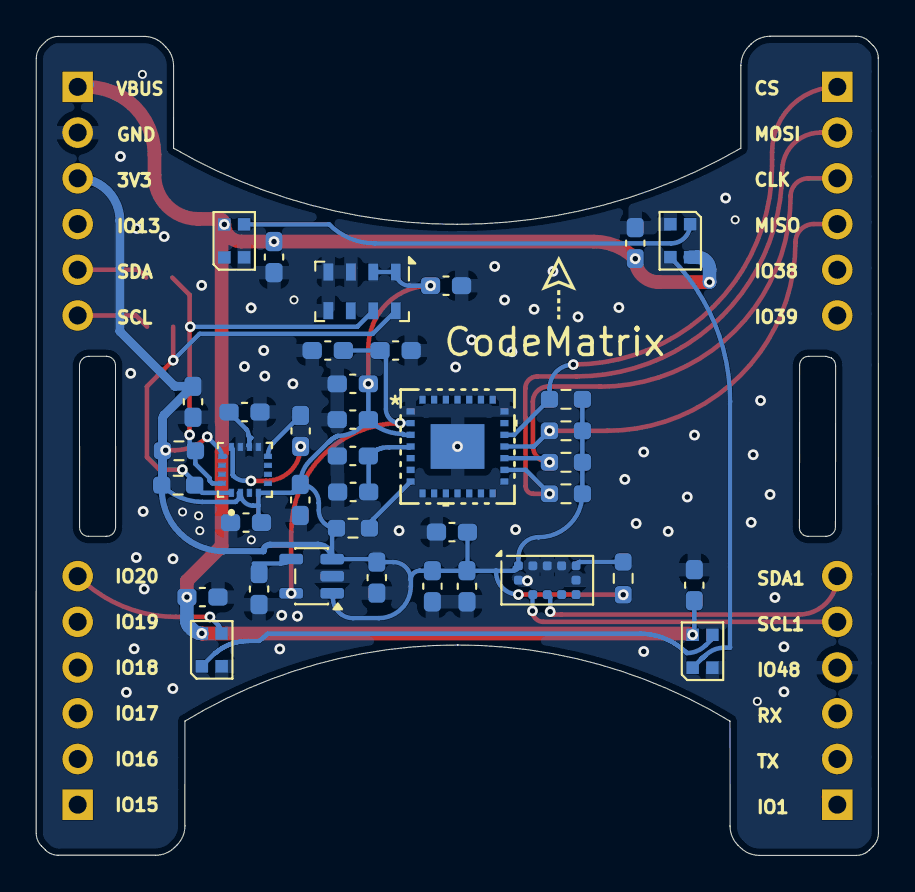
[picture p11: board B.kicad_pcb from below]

Board: 2 copper layers, 46.8 x 45.5 mm, 44 parts (38 on the bottom side), 25 nets.

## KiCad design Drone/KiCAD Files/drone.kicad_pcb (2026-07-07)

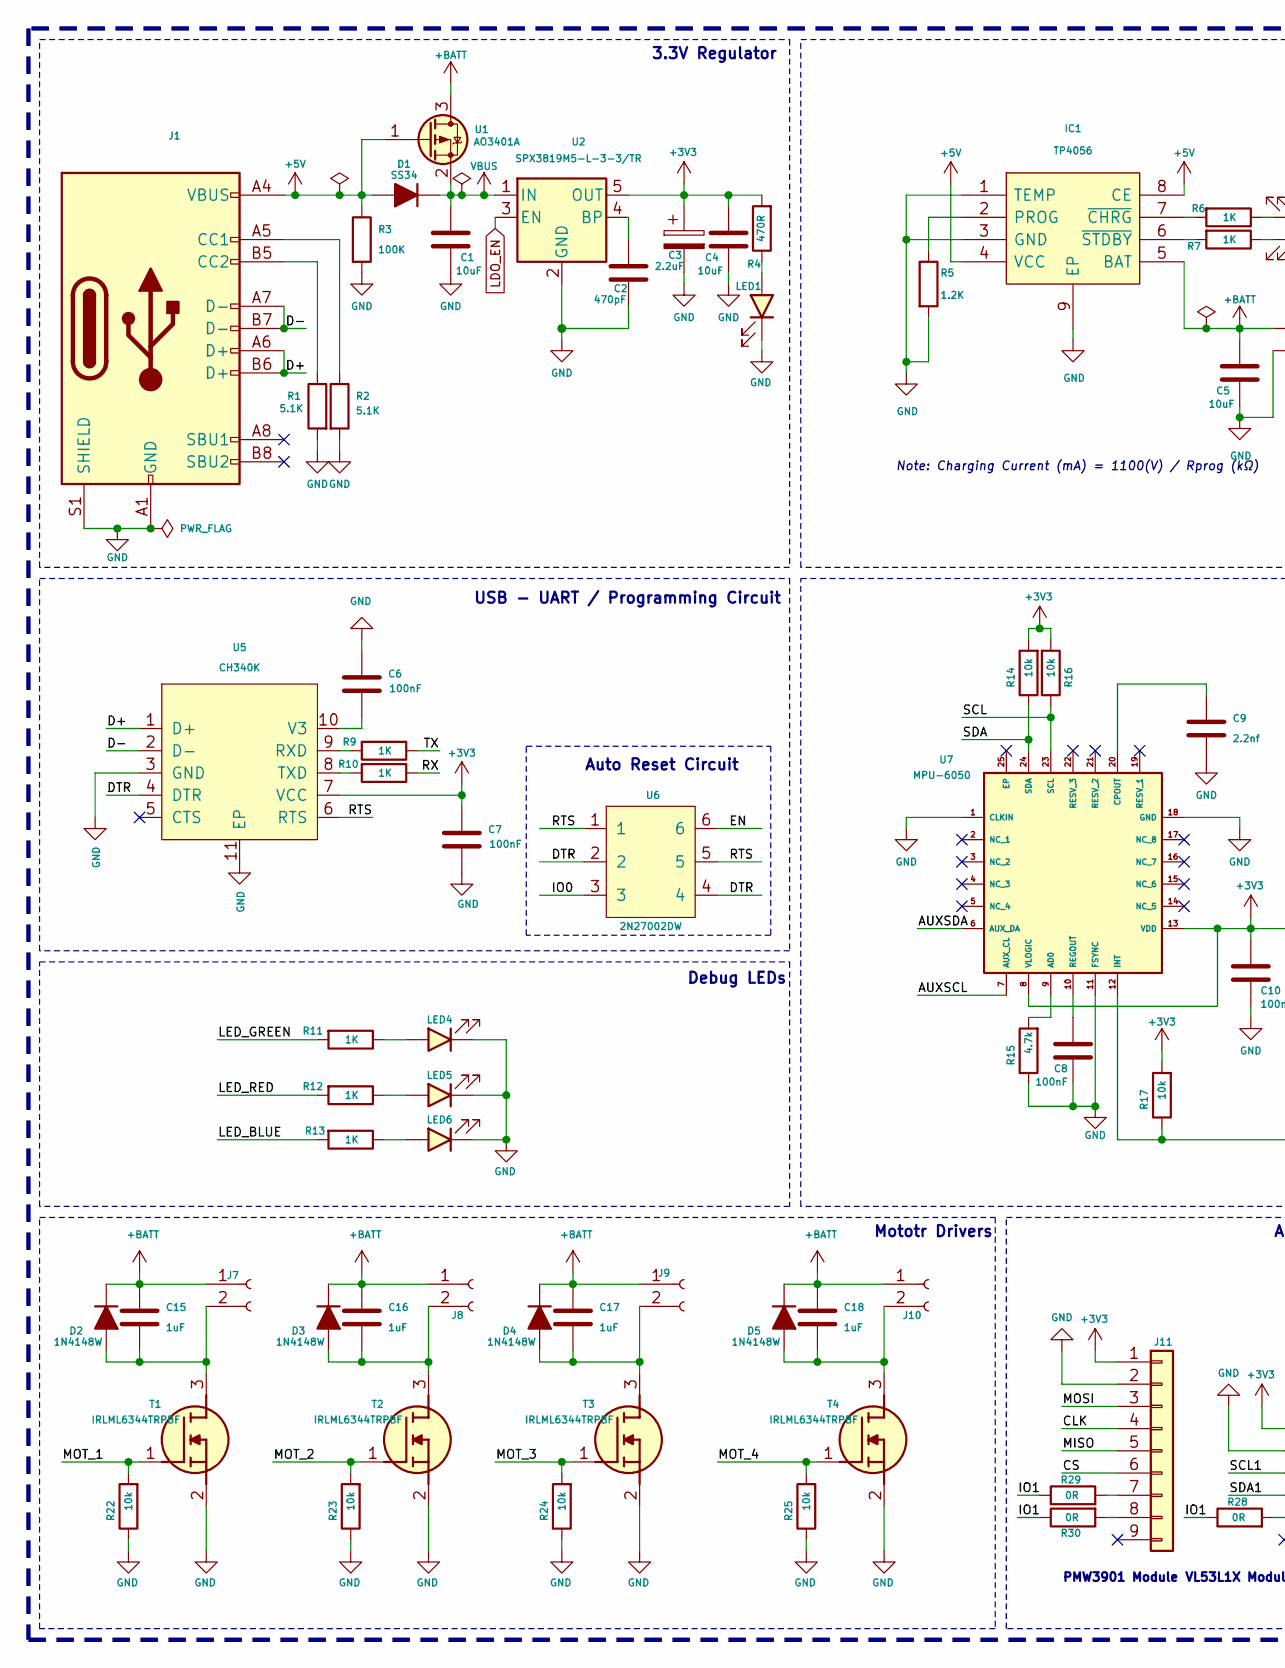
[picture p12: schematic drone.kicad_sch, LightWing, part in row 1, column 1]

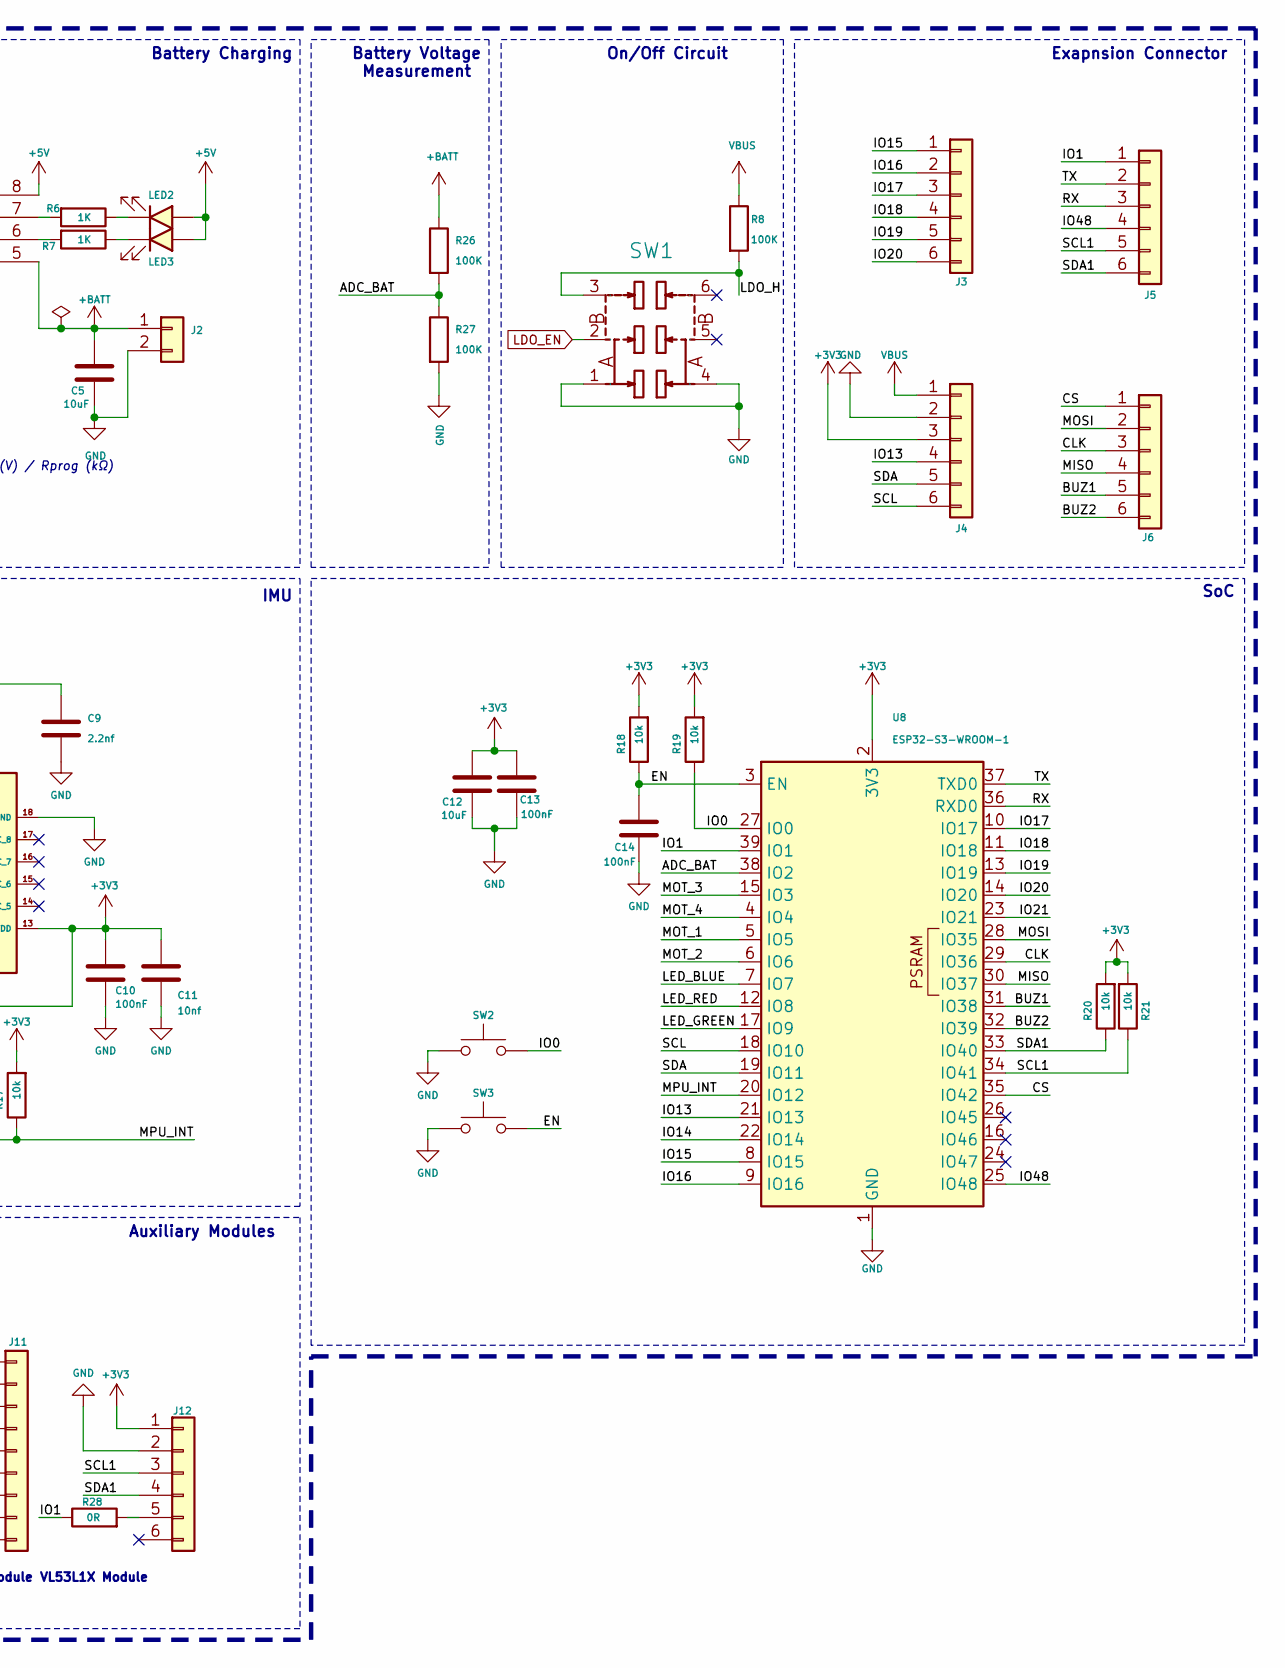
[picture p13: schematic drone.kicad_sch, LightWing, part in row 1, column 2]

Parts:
C1, C4, C5, C12: 10uF; C_0603_1608Metric; MFR.Part # CL10A106KP8NNNC; LCSC Part # C19702
C2: 470pF; C_0603_1608Metric; MFR.Part # 0603B471K500NT; LCSC Part # C1620
C3: 2.2uF; C_0805_2012Metric; MFR.Part # TCC0805X7R225M250FT; LCSC Part # C5448893
C6, C7, C8, C10, C13, C14: 100nF; C_0603_1608Metric; MFR.Part # CC0603KRX7R9BB104; LCSC Part # C14663
C9: 2.2nf; C_0603_1608Metric; MFR.Part # 0603B222K500NT; LCSC Part # C1604
C11: 10nf; C_0603_1608Metric; MFR.Part # 0603B103K500NT; LCSC Part # C57112
C15, C16, C17, C18: 1uF; C_0603_1608Metric; MFR.Part # CL10A105KB8NNNC; LCSC Part # C15849
D1: SS34; D_SMA; MFR.Part # SS34; LCSC Part # C8678
D2, D3, D4, D5: 1N4148W; D_SOD-123F; MFR.Part # 1N4148W; LCSC Part # C81598
IC1: TP4056; SOIC127P600X175-9N; MFR.Part # TP4056; LCSC Part # C20199357
J1: USB_C_Receptacle_USB2.0; USB_C_Receptacle_HRO_TYPE-C-31-M-12; MFR.Part # USB-TYPE-C-018; LCSC Part # C2927038
J2: JST XH 2P 2.50mm SMD Hoz; CONN-TH_2P-P2.50_XH-2AW; MFR.Part # XH-2AW; LCSC Part # C33132
J3, J4, J5, J6: Conn_01x06; PinHeader_1x06_P2.54mm_Vertical
J7, J8, J9, J10: Conn_01x02_Female; LiteWingMotor2
J11: Conn_01x09; PMW3901
J12: Conn_01x06; VL53L1X_BREAKOUT
LED1, LED2, LED5: LED_Red; LED_0603_1608Metric; MFR.Part # KT-0603R; LCSC Part # C2286
LED3, LED6: LED_Blue; LED_0603_1608Metric; MFR.Part # KT-0603B; LCSC Part # C2288
LED4: LED_Green; LED_0603_1608Metric; MFR.Part # LTST-C193TGKT-5A; LCSC Part # C12065
R1, R2: 5.1K; R_0603_1608Metric; MFR.Part # 0603WAF5101T5E; LCSC Part # C23186
R3, R8, R26, R27: 100K; R_0603_1608Metric; MFR.Part # 0603WAF1003T5E; LCSC Part # C25803
R4: 470R; R_0603_1608Metric; MFR.Part # 0603WAF4700T5E; LCSC Part # C23179
R5: 1.2K; R_0603_1608Metric; MFR.Part # 0603WAF1201T5E; LCSC Part # C22765
R6, R7, R9, R10, R11, R12, R13: 1K; R_0603_1608Metric; MFR.Part # 0603WAF1001T5E; LCSC Part # C21190
R14, R16, R17, R18, R19, R20, R21, R22, R23, R24, R25: 10k; R_0603_1608Metric; MFR.Part # 0603WAF1002T5E; LCSC Part # C25804
R15: 4.7k; R_0603_1608Metric; MFR.Part # 0603WAF4701T5E; LCSC Part # C23162
R28, R29, R30: 0R; R_0603_1608Metric; MFR.Part # 0603WAF0000T5E; LCSC Part # C21189
SW1: MST22D18G2_125; SW-SMD_MST22D18G2; MFR.Part # MST22D18G2 125; LCSC Part # C2906280
SW2, SW3: Tactile Switch 3x4x2; Tactile 3x4x2mm TS-A010; MFR.Part # TS-KG88C-ART25F; LCSC Part # C2874433
T1, T2, T3, T4: IRLML6344TRPBF; SOT95P237X112-3N; MFR.Part # IRLML6344TRPBF-HXY; LCSC Part # C6285738
U1: AO3401A; SOT-23; MFR.Part # AO3401A; LCSC Part # C15127
U2: SPX3819M5-L-3-3/TR; SOT-23-5; MFR.Part # SPX3819M5-L-3-3/TR; LCSC Part # C9055
U5: CH340K; ESSOP-10_3.9x4.9mm_P1.00mm; MFR.Part # CH340K; LCSC Part # C18208922
U6: 2N27002DW; SOT-363_SC-70-6; MFR.Part # 2N27002DW; LCSC Part # C5190214
U7: MPU-6050; MPU6050; MFR.Part # MPU-6050; LCSC Part # C24112
U8: ESP32-S3-WROOM-1; MFR.Part # ESP32-S3-WROOM-1-N8; LCSC Part # C2913198

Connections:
+3V3: C3.1, C4.1, C7.1, C10.1, C11.1, C12.1, C13.1, J4.3, J11.1, J12.1, R4.2, R14.2, R16.2, R17.2, R18.2, R19.2, R20.2, R21.2, U2.5 (OUT), U5.7 (VCC), U7.8 (VLOGIC), U7.13 (VDD), U8.2 (3V3)
+5V: D1.2 (A), IC1.4 (VCC), IC1.8 (CE), J1.A4 (VBUS), J1.A9 (VBUS), J1.B4 (VBUS), J1.B9 (VBUS), LED2.2 (A), LED3.2 (A), R3.1, U1.1 (G)
+BATT: C5.1, C15.1, C16.1, C17.1, C18.1, D2.1 (K), D3.1 (K), D4.1 (K), D5.1 (K), IC1.5 (BAT), J2.1, J7.1, J8.1, J9.1, J10.1, R26.1, U1.3 (D)
/ADC_BAT: R26.2, R27.1, U8.38 (IO2)
/AUXSCL: U7.7 (AUX_CL)
/AUXSDA: U7.6 (AUX_DA)
/BUZ1: J6.5, U8.31 (IO38)
/BUZ2: J6.6, U8.32 (IO39)
/CLK: J6.3, J11.4, U8.29 (IO36)
/CS: J6.1, J11.6, U8.35 (IO42)
/D+: J1.A6 (D+), J1.B6 (D+), U5.1 (D+)
/D-: J1.A7 (D-), J1.B7 (D-), U5.2 (D-)
/DTR: U5.4 (DTR), U6.2, U6.4
/EN: C14.1, R18.1, SW3.2, U6.6, U8.3 (EN)
/IO0: R19.1, SW2.2, U6.3, U8.27 (IO0)
/IO1: J5.1, R28.1, R29.1, R30.1, U8.39 (IO1)
/IO13: J4.4, U8.21 (IO13)
/IO14: U8.22 (IO14)
/IO15: J3.1, U8.8 (IO15)
/IO16: J3.2, U8.9 (IO16)
/IO17: J3.3, U8.10 (IO17)
/IO18: J3.4, U8.11 (IO18)
/IO19: J3.5, U8.13 (IO19)
/IO20: J3.6, U8.14 (IO20)
/IO21: U8.23 (IO21)
/IO48: J5.4, U8.25 (IO48)
/LDO_H: R8.2, SW1.3
/LED_BLUE: R13.2, U8.7 (IO7)
/LED_GREEN: R11.2, U8.17 (IO9)
/LED_RED: R12.2, U8.12 (IO8)
/MISO: J6.4, J11.5, U8.30 (IO37)
/MOSI: J6.2, J11.3, U8.28 (IO35)
/MOT_1: R22.2, T1.1 (G), U8.5 (IO5)
/MOT_2: R23.2, T2.1 (G), U8.6 (IO6)
/MOT_3: R24.2, T3.1 (G), U8.15 (IO3)
/MOT_4: R25.2, T4.1 (G), U8.4 (IO4)
/MPU_INT: R17.1, U7.12 (INT), U8.20 (IO12)
/RTS: U5.6 (RTS), U6.1, U6.5
/RX: J5.3, R10.1, U8.36 (RXD0)
/SCL: J4.6, R16.1, U7.23 (SCL), U8.18 (IO10)
/SCL1: J5.5, J12.3, R21.1, U8.34 (IO41)
/SDA: J4.5, R14.1, U7.24 (SDA), U8.19 (IO11)
/SDA1: J5.6, J12.4, R20.1, U8.33 (IO40)
/TX: J5.2, R9.1, U8.37 (TXD0)
GND: C1.2, C2.2, C3.2, C4.2, C5.2, C6.1, C7.2, C8.2, C9.2, C10.2, C11.2, C12.2, C13.2, C14.2, IC1.1 (TEMP), IC1.3 (GND), IC1.9 (EP), J1.A1 (GND), J1.A12 (GND), J1.B1 (GND), J1.B12 (GND), J1.S1 (SHIELD), J2.2, J4.2, J11.2, J12.2, LED1.1 (K), LED4.1 (K), LED5.1 (K), LED6.1 (K), R1.2, R2.2, R3.2, R5.2, R15.1, R22.1, R23.1, R24.1, R25.1, R27.2, SW1.1, SW1.4, SW2.1, SW3.1, T1.2 (S), T2.2 (S), T3.2 (S), T4.2 (S), U2.2 (GND), U5.3 (GND), U5.11 (EP), U7.1 (CLKIN), U7.11 (FSYNC), U7.18 (GND), U8.1 (GND), U8.40 (GND), U8.41 (GND)
LDO_EN: SW1.2, U2.3 (EN)
unnamed: C15.2, D2.2 (A), J7.2, T1.3 (D)
unnamed: C16.2, D3.2 (A), J8.2, T2.3 (D)
unnamed: C17.2, D4.2 (A), J9.2, T3.3 (D)
unnamed: C18.2, D5.2 (A), J10.2, T4.3 (D)
unnamed: IC1.2 (PROG), R5.1
unnamed: IC1.7 (~CHRG), R6.2
unnamed: IC1.6 (~STDBY), R7.2
unnamed: J1.A5 (CC1), R2.1
unnamed: J1.B5 (CC2), R1.1
unnamed: J11.7, R29.2
unnamed: J11.8, R30.2
unnamed: J12.5, R28.2
unnamed: LED1.2 (A), R4.1
unnamed: LED2.1 (K), R6.1
unnamed: LED3.1 (K), R7.1
unnamed: LED4.2 (A), R11.1
unnamed: LED5.2 (A), R12.1
unnamed: LED6.2 (A), R13.1
unnamed: C2.1, U2.4 (BP)
unnamed: R9.2, U5.9 (RXD)
unnamed: R10.2, U5.8 (TXD)
unnamed: C6.2, U5.10 (V3)
unnamed: R15.2, U7.9 (AD0)
unnamed: C9.1, U7.20 (CPOUT)
unnamed: C8.1, U7.10 (REGOUT)
VBUS: C1.1, D1.1 (K), J4.1, R8.1, U1.2 (S), U2.1 (IN)

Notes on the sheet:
Note: Charging Current (mA) = 1100(V) / Rprog (kΩ)
IMU
VL53L1X Module
Debug LEDs
Battery Charging
3.3V Regulator
Battery Voltage Measurement
Auto Reset Circuit
USB - UART / Programming Circuit
SoC
Mototr Drivers
Exapnsion Connector
Auxiliary Modules
On/Off Circuit
PMW3901 Module

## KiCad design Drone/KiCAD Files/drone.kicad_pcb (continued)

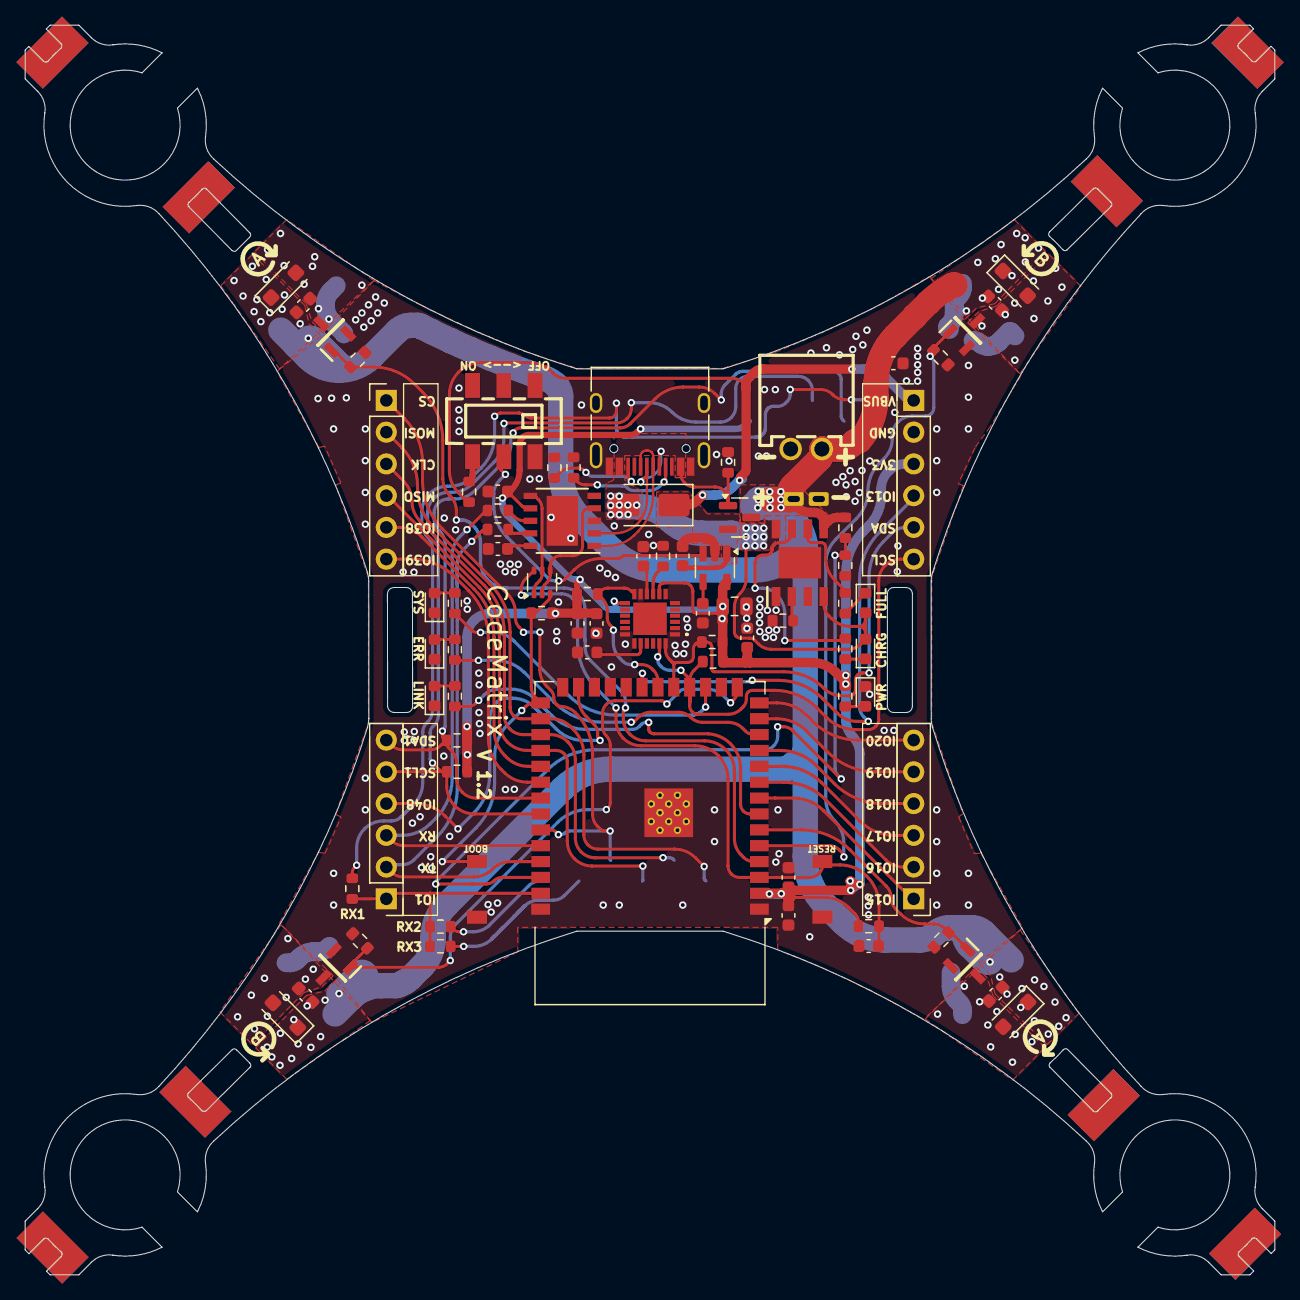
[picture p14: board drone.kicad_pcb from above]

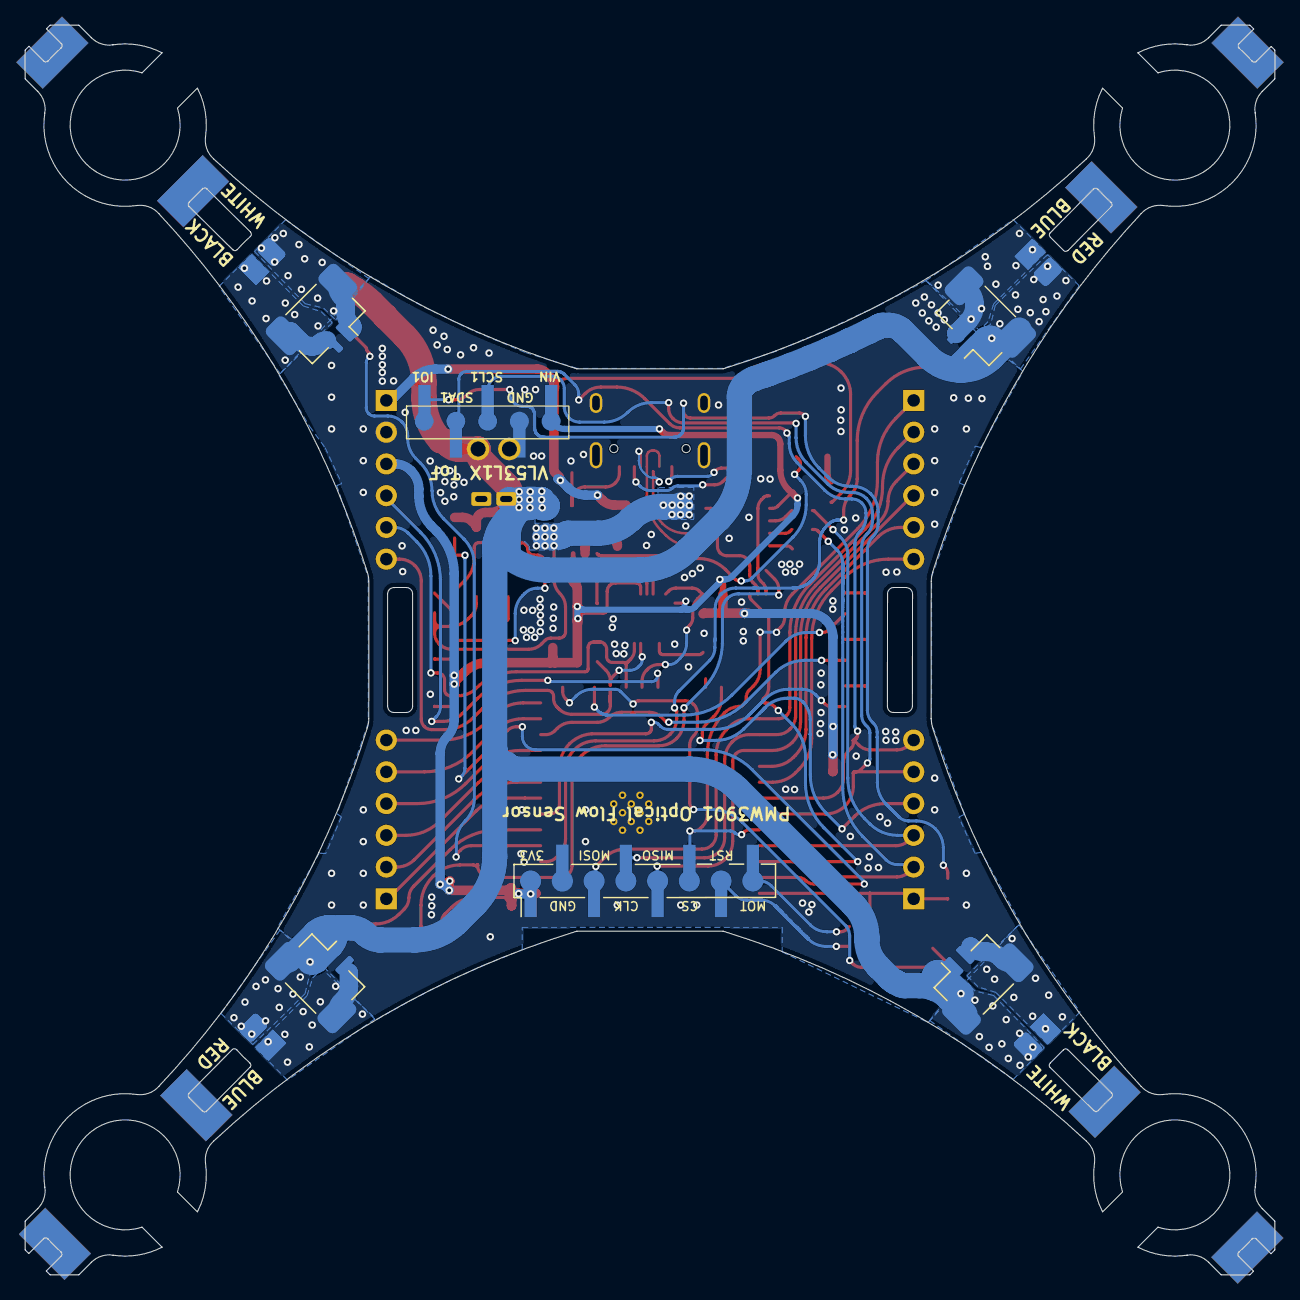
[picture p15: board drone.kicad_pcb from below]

Board: 2 copper layers, 100.0 x 100.0 mm, 85 parts (2 on the bottom side), 68 nets.

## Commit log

2026-07-07 Update README with ESP32 Drone Positioning Module info
    Added details about the ESP32 Drone Positioning Module, including its features and compatibility with CodeMatrix and LiteWing Drones.
2026-07-07 Revise README for CodeMatrix ESP32 Drone
    Updated the README to improve clarity and consistency in naming. Added sections for introduction and features of the CodeMatrix ESP32 Drone and its positioning module.
2026-07-07 Refine README for CodeMatrix ESP32 Drone
    Removed redundant section header and updated the introduction for clarity. Added details about the ESP32 Drone Positioning Module.
2026-07-07 Update README with introduction for CodeMatrix module
    Added introduction section for CodeMatrix ESP32 Drone Positioning Module.
2026-07-07 Create Drone Stand Gerber
2026-07-19 Add introduction for ESP32 Drone Positioning Module PCB
    Added introduction section for the ESP32 Drone Positioning Module PCB, highlighting its features and manufacturing benefits.
2026-07-19 Add image to ESP32 Drone Bluetooth Speaker Module
    Added an image to the introduction of the ESP32 Drone Bluetooth Speaker Module section.
2026-07-19 Add image to ESP32 Drone Bluetooth Speaker Module intro
    Added an image to the introduction section of the ESP32 Drone Bluetooth Speaker Module.
2026-07-19 Update introduction for ESP32 Drone Bluetooth Speaker Module
    Updated the introduction section to indicate that the ESP32 Drone Bluetooth Speaker Module is coming soon.
